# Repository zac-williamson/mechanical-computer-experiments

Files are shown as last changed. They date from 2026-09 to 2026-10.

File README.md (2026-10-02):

# Mechanical computer modules

Build the next 1-bit register from a small collection of reusable mechanical modules. Only these two designs are active:

| Active design | Entry points |
|---|---|
| Modular actuator, carriage and locking bolt | [Viewer](modular-actuator-carriage/Viewer.html) · [Design and print files](modular-actuator-carriage/README.md) · [Build and validation](modular-actuator-carriage/Source/README.md) |
| Latched 1-bit register | [Viewer](planar-register/register-from-multiplexer/Planar%20register/Viewer.html) · [Design, sources and checks](planar-register/README.md) |

Start with the modular actuator/carriage module when developing reusable components. Keep the latched 1-bit register as the assembly reference. It is a level-sensitive write-enabled latch, not the archived clocked master–slave register.

Read [AGENTS.md](AGENTS.md) before making changes. CAD checks do not establish physical strength, friction, wear or reliable switching; consult each design's reported limitations.

All other designs are in [archive/](archive/README.md). They are historical references, not current candidates or starting points. Do not revive them unless explicitly requested.

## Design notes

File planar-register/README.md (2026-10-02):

# Planar register — preserved latch prototype

[Assembly viewer](register-from-multiplexer/Planar%20register/Viewer.html) · [Print layout STL](register-from-multiplexer/Planar%20register/Print%20layout.stl) · [Design and checks](register-from-multiplexer/Planar%20register/README.md)

This preserves the planar write-enabled latch, including the detachable pinned guide and restored rear bolt-retaining lips. It is not an edge-triggered register. The print layout has 20 printed parts. Geometry checks do not establish physical load capacity; the whole-register closing-data race remains unresolved.

This is one of the two active designs. The separate clock-triggered development is archived in `../archive/clocked-planar-register/`; it is not the current assembly reference. Do not overwrite this latch with that design.

## Sources and reproducibility

The original relative directory structure is retained so source scripts keep their paths. `register-from-multiplexer/Source/` contains the generators, viewer publisher and checks. `work/register-before-left-cam` and `work/register-mux-reference/multiplexer` are frozen build inputs, not alternate current multiplexer designs. `Snapshot hashes.json` records byte-exact copies from the working design.

Run `python restore_validation_workspace.py` to reconstruct the validation working directory from the published snapshot. Install `requirements.txt` into an isolated environment. The source README describes the full development build; native-part regeneration additionally requires the BrickLink Studio LDraw library at its documented path. The full build retains assertions for unresolved whole-assembly issues and is not advertised as passing end-to-end.

The focused checks for this revision are `check_bolt_y_restraint.py`, `check_detachable_guide.py`, `check_support_free_prints.py`, `check_frame_printed_clearance.py`, `check_frame_native_contacts.py` and `check_restored_bearings.py`. Published reports accompany the model. No Bambu Studio slicer was used.

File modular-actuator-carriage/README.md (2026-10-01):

# Modular actuator, carriage and locking bolt

Snapshot of the current tested-in-CAD prototype, saved 2 October 2026.

- [Model viewer](Viewer.html), including motion, exploded, print and tiled views.
- [Complete print layout](Print%20layout.stl).
- [Carriage-only print layout](Carriage%20print%20layout.stl).
- Individual `print.stl` files use the recorded print orientations; other component STLs use assembly coordinates. Units are millimetres.

The module tiles on a 72 mm X by 64 mm Z pitch. X follows rods/axles; Z indexes rows; +Y points toward the rear/base. Rod end coupling holes have 7 mm spacing (X = ±32.5 and ±39.5), with two separate pins per joint. Revised rod ends must mate to revised ends. One-pin joints have not been physically validated.

Recent changes include reinforced carriage fork struts, removal of a redundant carriage arm and square shoulder, rounded locking-rod cam-extension tips, and closer rod coupling holes.

## Validation and limitations

The included latest clearance report covers 26 prescribed motion poses; the tiling report covers neighbouring modules and connector insertion. These are geometric checks, not physical force, wear or strength tests. Rod print checks compare layer growth with the previous geometry; existing pin-hole roof overhang flags remain. The complete assembly is NOT certified support-free. Review the slicer preview before printing, particularly carriage overhangs and hole roofs.

[Build and validation instructions](Source/README.md) provide a self-contained rebuild from bundled mesh inputs, plus the full historical Python sources. This is a mesh-based CAD workflow, not a fully parameterized model. `Model.json`, component STLs, and the self-contained viewer preserve the current geometry. Development history is summarized in `Compact module notes.md`; historical claims there should be read with their revision context. `Snapshot hashes.json` records every exported file.

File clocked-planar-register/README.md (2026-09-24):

# Clocked planar register

[Open the current compact model](Compact%20layout.html). It retains the planar register's actuator cores and uses four worm actuators, five clutch rings and eight elastic bands. The earlier full-size assembly remains in `Viewer.html`; the unclocked planar register and multiplexer are separate, preserved designs.

The compact model has direction-coded D, WRITE and CLK inputs, continuous POWER, and Q on the opposite X side. Its two storage stages form a master/slave register. WRITE selects D or feedback Q before the master, avoiding a gated-clock edge when WRITE changes.

- [Current arrangement and sequencing](Compact%20layout/Design.md)
- [Validation evidence and unresolved requirements](Compact%20layout/Validation%20status.md)

The animation uses the same contact-corrected poses as the printed-part collision checks. Native clutch angular windows determine engagement and reversal backlash; a fixed time delay is no longer used. The animation is a quasi-static model, not a physical load test.

Every geometry report must match the current geometry hash. Historical full-size reports, old fixed-delay traces and static assembly-reference poses do not qualify the current compact mechanism. The qualification summary fails closed when required evidence is absent or stale.

## Reproduction order

Use the existing `work/register-print-env/bin/python` environment from the workspace root. Sources are under `current-designs/clocked-planar-register/Source/`.

1. `compact_layout.py` generates parts and the static viewer.
2. `check_compact_gear_phases.py` and `compact_clutch_profiles.py` derive native gear and clutch phases.
3. `compact_phase_operation.py` simulates all 112 transition/initial-Q cases; `compile_compact_contacts.py` resolves actuator contact poses.
4. Run the geometry, motion, retention, timing, load and print screens listed in the validation status.
5. `publish_compact_motion.py` publishes the animation; `compact_qualification_status.py` reports remaining qualification requirements.

Printed structure, materials, band preload, motor acceleration, joint grip and loaded friction are not established by the nominal motion trace. Do not treat a successful script exit as a working-machine certificate.

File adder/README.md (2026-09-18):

# 1-bit adder

Single-level shared-actuator layout: 292 × 111 mm base, 39 printed parts, 30 gears, three actuators and four clutches.

B′ = B XOR SUB; P = B′ XOR Cin; SUM = P XOR A; Cout = P ? A : B′.

Cin drives only its worm actuator. P drives the shared carry/sum actuator; the pinned carriage tie operates both clutches. The carry data drive comes from local A or B′, so Cin does not power a chain of downstream clutch gears.

`Viewer.html` includes axle labels, part selection, pan and axes. The common carriage, lever and bridge meshes come from ../multiplexer. Carry and sum have local shaft-clearance and tie attachment adaptations. The sum fork has no independent lever or upper actuator frame.

This is an engineering prototype, not a print release. The three actuator carriages have a rounded inside-roof relief for the fixed pivot axle, sized for the full 8.675 mm stroke and 0.5 mm nominal radial clearance. Bearing positions, travel, gear count and external dimensions are unchanged.

Current checks pass: all 16 arithmetic cases, 12 gear-pitch checks, fixed supports, mounting and coupling pins, conservative native envelopes, and carriage travel. `Pivot clearance checks.json` checks a continuous swept axle envelope and verifies that the relief does not materially remove the lever's working contact surfaces over the prescribed switching trace (0.001 mm³ mesh tolerance).

A complete print-orientation audit and loaded shared-carriage test remain outstanding. No print layout is supplied. CAD checks do not establish printed friction, wear or loaded reliability.

Rebuild with Sources/build.py, Sources/gear_check.py, Sources/apply_phases.py, Sources/publish.py, then the audit scripts, including Sources/pivot_clearance_check.py. Python dependencies are in Sources/requirements.txt; LDraw is loaded from the local installation. Do not change stage spacing independently of stock axle lengths and connector positions.

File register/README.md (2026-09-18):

# 1-bit register

Position stores one bit. WRITE releases the spring-biased bolt before the input clutch drives the storage carriage. Output enable connects the powered stored value to BUS_OUT.

`Viewer.html` shows the complete assembly, input labels, individual parts and an illustrative operating sequence. `Assembly manifest.json` identifies all 37 printed parts and hardware; `LEGO parts.csv` is the hardware inventory.

Print `Print plate 1.stl` and `Print plate 2.stl`, or use the individually oriented files in `Print parts`. Inspect support placement around the original clutch fork. Do not assume these plates are support-free. Axle bores face vertically in the supplied orientations. Assemble with LEGO friction pins; each base-mounted bearing uses at least two pins. Use 4 elastic bands.

Slide the bolt into the integral front-bridge guide before installing the rear bridge. Install the follower and cam, then the return band. The cam withdraws the bolt 5.2 mm. Only relock with the storage/test carriage at one of its end pockets. Check free motion by hand before applying drive torque.

Current geometric results are recorded in `Printed clearance checks.json`, `Lock checks.json` and `Print checks.json`. These do not validate loaded operation or ABS tolerances. The actuator's physical reliability remains under test.

## Rebuild

Use Python with `Source/requirements.txt` and an installed LDraw library. Run `Source/build.py`, `Source/print_layout.py`, then `Source/publish.py`; run the check scripts after changes. The generator references ../multiplexer directly. No slicer application is required.

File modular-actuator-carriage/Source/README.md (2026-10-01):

# Rebuilding and validating this module

Run from the repository root on macOS/Linux (the throttler uses POSIX signals). The captured environment uses Python 3.14.

```sh
python3.14 -m venv .venv-modular
.venv-modular/bin/pip install -r modular-actuator-carriage/Source/requirements.txt
.venv-modular/bin/python modular-actuator-carriage/Source/work/run_queued_cool_job.py modular-actuator-carriage/Source/rebuild.py
```

The serial runner limits geometry work to one worker at 10% duty and guards memory. It fails closed if the installed Manifold library lacks the expected TBB control API. Output goes to `Source/build/`; committed print files are never overwritten by this command.

## Inputs and editing

`Inputs/` contains the complete assembly and print meshes, viewer animation, and coupling hardware immediately before the final rod-hole-spacing revision. It is intentional source geometry, not a download cache. `rod-pin-spacing/build.py` applies the last hole relocation and rebuilds Model.json, the viewer, individual rod STLs and the full plate. Change the explicit 0.5 mm shifts consistently in rod cuts and coupling-pin placement if editing that parameter. The other components are preserved from their bundled mesh inputs. This design was developed by successive mesh booleans; it is not a fully parameterized CAD model.

`History/` preserves ALL 307 original project Python scripts, including builders, analyses, packaging and validation. These are historical reference, not the supported entry point: many retain original local paths or depend on obsolete candidate snapshots. Use them to understand the geometric construction, then port the desired operation to the current pipeline with the current Inputs. Do not run an old publisher against the current design. No historical private workspace paths are needed for the supported rebuild.

`Switching trace.json`, `native_envelopes.py`, the single-band geometry and the seam-cleaning helper are bundled dependencies. Native hardware meshes are already embedded in Model.json; LEGO Studio is not needed to rebuild or validate the current revision.

## Tests and limits

Rebuild runs 26 mechanism poses, 2x2 tiling and connector insertion, carriage installation around the preassembled actuator, watertightness, and print-oriented layer-growth comparison. Existing rod hole-roof overhang flags are retained and printed; the comparison is not a support-free certificate. Contact exclusions and conservative native-part envelopes are documented in validation code. Test reports establish geometry only, not physical load capacity or reliable operation.

Never infer physical validation from `passed`. Read module README.md, AGENTS.md and Compact module notes.md before editing.

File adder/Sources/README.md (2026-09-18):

See ../README.md. Common actuator source: ../../multiplexer. This is an unprinted engineering prototype.

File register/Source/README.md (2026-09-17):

# Regenerating this prototype

Use Python 3 with the packages in requirements.txt. Set LDRAW_DIR to an installed LDraw library containing parts/ and p/. The default points to the existing Studio 2.0 LDraw library on macOS. No slicer is invoked.

Run build.py, then print_layout.py and publish.py. For verification run check.py, native_check.py, mount_check.py and gear_check.py. Run scripts from this directory or by absolute path. Outputs go to the parent directory; set REGISTER_OUTPUT to a different existing directory to generate a separate copy.

Inputs contains the final multiplexer mesh components and its reference assembly/pose data used by this design, not intermediate design iterations. New structures are parameterised in build.py; inherited actuator components are mesh inputs. This is not a fully parametric solid-CAD model. Viewer.html in Inputs is reference data, not the new register viewer.

LEGO visualisation geometry is loaded from your local LDraw installation. LDraw part authors retain their respective credits and licence terms; those part source files are not redistributed here. The embedded reference and output viewers include derived visualisation meshes. LEGO is a trademark of the LEGO Group; this is an independent prototype.

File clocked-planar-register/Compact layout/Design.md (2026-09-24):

# Compact clocked register

The current static complete-assembly envelope is **278.4 × 127.2 mm in XZ**, a **50.42% area reduction** from the earlier full-size clocked assembly. Overall Y depth is **76.23 mm**, reduced from 99.4 mm. These include shafts, retainers and frame, but are reference-pose dimensions rather than a swept-motion packaging claim.

## Components and routing

There are four planar-derived worm actuators: WRITE selector, master storage, output storage and CLOCK sequencer. Five clutch rings comprise the WRITE selector, two storage outputs and two input-disconnect gates. Eight elastic loops serve four actuator returns, two bolts and two passive fork biases.

D, WRITE, CLK and POWER enter the negative-X side; Q exits positive X. CLOCK uses one reversing mesh. Its inversion is absorbed by the sequencing direction. The selected signal uses one mesh to the master gate; master output directly drives the slave gate input. Q feedback uses one axle and one mesh at either end. The D header's single mesh is oriented in Y around its receiving shaft to clear the master ring without an additional idler or greater Y envelope.

Each storage power branch has unit speed magnitude. Master and slave clutch-side assignments differ to absorb the interstage inversion. The model checks the actual Q shaft's angular velocity; its settled ratio to POWER is +1 or -1, not a value inferred merely from carriage position.

## Clock sequence

The original clock actuator drives a 12 mm / 30 mm amplifier. Its approximately ±3.75 mm stroke produces approximately ±9.375 mm common-bar travel. A rising clock withdraws master drive, permits the master bolt to seat, lifts the output bolt and admits master data to the output actuator. Falling clock reverses the sequence.

Each input fork has 4 mm of one-sided float: elastic bias permits its dogs to wait for angular alignment, while the bar positively withdraws it. The rear fork guides retain their compact positions; only each front clutch finger is offset 6 mm. The gate gears sit alongside their LEGO clutch connectors. Nominal first tip contact is at 6.8 mm bar travel, before full insertion. The model tracks the measured CAD angular windows and about 64 degrees of dog backlash.

Changes to D or WRITE at the capture boundary violate the setup/hold assumption. Those cases are explicitly indeterminate rather than assigned a guaranteed bit. Four such nominal cases leave the master outside a locking pocket. The mechanism must not be described as accepting arbitrary asynchronous captures.

## Structure and manufacture

Supports follow the actual shaft and pin datums. All sixteen routing shaft stacks have opposing nominal thrust faces; grip strength remains a separate requirement. Carriage halves retain bearing-flat print orientations.

The rear clock-pivot bearing is a separate bridge, attached with two non-collinear LEGO friction pins. Its bearing axis and amplifier position are unchanged. This removes the former roughly 31 mm unsupported ledge beneath the base's pivot region. The bridge prints flat on its Y face. Pin-bore roofs and counterbore lips still need bridge-quality verification; the common cam/fork bar has support-dependent features and is not designated support-free.

See [validation status](Validation%20status.md) for the current evidence, failures and limitations. The planar register and multiplexer have not been regenerated or modified by this work.

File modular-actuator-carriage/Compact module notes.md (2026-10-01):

# Compact module candidate

Base footprint: 72 mm X × 64 mm Z, X = −31.5 to +40.5, Z = −8 to +56. Base remains Y = 32 to 48.4; no increase in depth. Moving rod ends extend beyond the base to mate with adjoining modules.

The frame-joining holes remain at Z = 0 and 48, now X = −26 and +35. Only the left bearing-wall pins move along Z, to 10 and 38. The left wall has rear access gaps so connecting bridges can be pressed into place after the walls are mounted. Pin ends remain flush with the base underside at Y = 48.4.

Both rods are shortened 4 mm at each end, carrying their existing lap joints and holes inward. The actuator axle is 9L; the output axles are 4L each. Four half-bush retainers sit 0.8 mm farther inward, in shallow bearing recesses, leaving 0.2 mm to the external connectors. The 72 mm nominal pitch gives 8 mm nominal insertion into each end of a 2L connector. Exact physical seating against the smooth connector centre stop remains a fit test; the reference mesh has a 0.2 mm divider, and keyed mating contacts are excluded from clearance testing.

Checked: operating geometry, 2×2 neighbouring modules with independent rows, bridge and rod-pin insertion, watertight printable components. These are geometric tests, not loaded-operation or physical print validation. Use the updated base, both walls, both rods and frame bridges together; do not mix their positions with the 80 mm version. The carriage, actuator cheeks, bolt and guide geometry are unchanged.

## Rebuilt base

The base now consists of a rear plate and explicit mounting blocks. All four bearing-wall pins have 8 mm-deep sockets; the relocated lower-left socket no longer opens into empty space. Frame-joining pins remain flush with the underside. Connector pockets are open spaces between blocks, without retained cut remnants. The lower actuator bore has an intentional open mouth below Z = 29 on its front portion, removing the thin lip above the cheek clearance; its rear portion remains enclosed.

## Rebuilt left bearing wall

A new continuous 4 mm-thick web joins both mounting feet. The former central rear cutout is filled. The lower axle uses a 7 mm-radius circular boss with an angled shoulder into the wall; minimum radial material at its retainer recess is 3.15 mm. Pin centres, rod-guide clearances and the +X printing face remain unchanged. Rear access above and below the feet remains open for the frame bridges. The lower actuator bearing, rod guides and all mounting positions were checked against the moving module and tiled neighbours.

## Fork-root repair

Replaced the fork-root junction and adjacent brace sections with overlapping solids. Removed the residual thin cut surfaces. The clutch-contact region, worm bearing, locking detents and rod-pin mounting geometry are unchanged. Motion, tiling, carriage insertion and sampled 0.16 mm print-layer checks passed; this does not establish physical strength or friction.

Removed the residual thin bearing-transition projections from both carriage halves. The fork root, braces and working contact regions are unchanged. This change removes material only, so the prior clearance checks remain applicable; both updated parts passed solid and sampled print-layer checks.

Fork reinforcement: widened both 45-degree struts along Y from 2.2 to 3.4 mm (Y=1.55..4.95 and 9.3..12.7). Removed the left carriage cantilever toward the fork. Working worm bearings, clutch contact, detents and rod pin mounts unchanged. Passed 26 motion poses, tiled-module and insertion checks, and sampled 0.16 mm layer island checks. Physical strength and printer results remain untested. Updated matching carriage and complete print layouts.

Removed the unnecessary square shoulder above the fork struts (16.96 mm3 removed; no added material). Braces, fork contact, bearings, detents and pin mounts unchanged. Previous motion/insertion clearances preserved by removal. IMPORTANT: whole-carriage 45-degree layer-growth review flags further overhangs; island checks do not establish support-free printing. See project AGENTS.md mandatory printability rules.

Rounded locking rod cam-extension shoulders with 2 mm root blends and 1.5 mm outer corner rounds in XY. Retained operating XZ curve, maximum Y19.6, bed Z40. Passed 26 motion poses and tiling/insertion checks. Layer-growth comparison at 0.2 mm finds no new steep overhangs; existing end pin-hole roof flags remain. Updated assembled, print-oriented STL and full plate.

Rounded the acute cam-extension tips in XZ using 1.2 mm profile rounding, blending back to the original rod root across Y14.2..16.2. Preserved flat bed Z40. Removal only, central cam X=-8..8 unchanged, one watertight solid, no new steep layer-growth flags at 0.2 mm. Existing pin-hole roof flags remain. Updated print STL and full layout.

Rod end pin spacing reduced 8 to 7 mm: X +/-32.5 and +/-39.5. Both rods and tiled pin hardware updated; nominal minimum outer counterbore ligament 1.05 to 1.55 mm. Original bore and roof profiles translated unchanged; end extents, stroke, cams and carriage attachments unchanged. Motion, 2x2 and insertion checks passed. Print layer growth areas no worse than baseline, existing pin-hole roof flags remain. Revised ends must mate to revised ends. One-pin use not physically tested.

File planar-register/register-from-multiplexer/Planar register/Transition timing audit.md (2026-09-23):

# Timing audit — revised cam

The updated model contains 108 examples across all 12 D/WRITE transitions, including both possible held bits and six assumed speed/phase profiles. It uses hysteretic ±0.4 mm clutch-ring play and first-contact coupling. Time is normalized, not calibrated to a particular motor.

There are no commanded motions through an inserted bolt in these nominal examples. However, the two simultaneous D-reversal / WRITE-closing transitions still have three invalid-HOLD examples each: the memory can stop between its pockets. Closing does not guarantee capture of the old bit. This is a latch timing problem, not cured by the stronger guide.

The animation is an event witness, not a force-driven simulation. It does not establish physical minimum/maximum motor response times, native tooth backlash, loaded release, coasting or freedom from every possible jam. See the JSON for individual cases and the main README for the mechanical checks.

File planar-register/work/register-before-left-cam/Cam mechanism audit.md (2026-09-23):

# Cam / roller / bolt: loaded mechanism review

**Decision: do not print the present complete mechanism as a confidence prototype. The short, offset bolt guide needs revision first.** This review isolates the cam lock; the master–slave architecture and simultaneous-input race are outside its scope.

## Findings from the actual geometry

| Item | Finding | Implication |
|---|---|---|
| Guide engagement | Guide is 7.6 mm high, but the rising stem leaves only 4.6 mm overlap at full lift. | The available bearing span shrinks exactly when the roller is highest. |
| Roller overhang | Near the end of the straight ramp, its centre is 9.94 mm above the guide top; at full lift, 11.8 mm. | Horizontal cam force creates a large overturning moment. |
| Rear offset | Roller centre Y27.6; guide centre Y19.6: 8 mm offset. | Even the upward lifting force twists the bolt into the guide walls. |
| Band offset | Its attachment is approximately 7.4 mm to one side and 1 mm forward of guide centre. | Increasing band strength also increases the tendency to cock the bolt; it is not a cure for a bad guide. |
| Guide play | ±3° tilt with ±0.15 mm translation causes **zero solid intersection** between the complete bolt and guide in 12 checked raised poses. Roller X shifts 0.83–0.89 mm. | The previous total 0.6 mm timing-error assumption is unsupported by the guide alone, before print error, pin play or flex. Other parts/cam were absent in this test; it is not a proof of an assembled tilted trajectory. |

The previously published friction formula accounted only for direct lateral force. It omitted the overhang moment, rear offset and return-band eccentricity. **Its apparent friction margin must not be used.**

## Force and flex screen

A rectangular-guide Coulomb-friction calculation balances the cam force and the wall reactions at both ends of the actual remaining stem overlap. It treats the cam roller as ideal, assumes a 2 N band, and varies friction rather than claiming a measured PLA coefficient.

Near WRITE displacement −0.45 mm (bolt lift 5.94 mm), the screen gives:

| Assumed guide friction coefficient | Required upward roller force | Horizontal cam force | Existing gross-beam cam deflection |
|---|---:|---:|---:|
| 0 | 2.0 N | 3.6 N | 0.019 mm |
| 0.05 | 3.54 N | 6.37 N | 0.033 mm |
| 0.10 | 87.2 N | 157 N | 0.81 mm |
| 0.15 or greater | No positive sliding equilibrium in this screen | — | — |

These are **conditional sensitivity results**, not predicted measured forces or a certified critical coefficient. Face-friction moments, compliance, local corner contact, bush drag and material variation are not solved. They show why the earlier “a 2 N band implies a lightly loaded cam” argument was inadequate. The calculated critical region is sensitive enough that this guide is a poor first-print candidate.

The gross-beam deflection uses the earlier unperforated cam approximation, assumed E=1800 MPa and rigid attachment. Pin-hole stress concentration, shear-key fit, local bearing and frame movement remain excluded; 0.81 mm is not a verified assembly deflection. It demonstrates that modest band tension can produce large structural demand when guide reactions amplify friction. A detailed FEA of the cam alone would not resolve the more fundamental guide/contact uncertainty.

A separate bolt-stem beam screen under residual keeper side load predicts approximately 23.8 MPa bending stress at 50 N and 47.7 MPa at 100 N, using a 5.8 mm tip lever arm. These are screening forces, **not** a demonstrated mapping from 0.1 Nm input torque. The actual distributed keeper contact, guide support, printed orientation and load release need measurement. The bolt must not routinely be asked to release against a driven memory actuator.

With the cam removed from contact, the off-centre band can also cock the raised bolt. The simple guide model's return friction limit falls from about 0.45 at low lift to 0.27 at full lift. A stronger band scales both useful pull and friction-generating reaction together.

## What must change in the mechanism

1. **Guide the roller carrier near where the force enters.** Use two separated guide lands or a guided crosshead, keeping the roller within their support span rather than above a short stem sleeve.
2. **Maintain guide overlap through the entire lift.** Do not lose almost half the bearing length when opening.
3. **Centre the cam and return-band loads on the supported carrier as closely as possible.** Keep the narrow locking tip as an extension of that supported carrier; do not use it as the sole anti-tilt guide.
4. **Recalculate the cam sequencing with actual maximum play plus flex.** Do not recover timing margin by assuming a tighter print than the 0.4 mm-nozzle process supplies.
5. **Check attachment and frame deflection together.** Thickening the orange plate alone would transfer increased force into the guide and LEGO-pin joint without curing wedging.

These are design requirements, not an integrated CAD revision. No assembly STL has been altered in this review. Once the carrier layout is chosen, its complete travel and print orientation need new checks before it becomes a print candidate.

## Small-test scope after that revision

The existing `Latch coupon` tests an earlier bolt/keeper arrangement moving along Y. It does **not** reproduce this Z-moving cam, roller offsets, guide overlap or orange pin joint, and must not be used to qualify them.

The useful replacement test assembly must reproduce the actual cam, roller/axle/retainer, carrier guide, band anchors, keeper, and cam mounting joint. Drive the cam manually first, measuring force through the full stroke in both directions and at both keeper positions. Then use the actual WRITE actuator. Preserve representative support spans so the fixture does not hide frame flex.

Record: printed dimensions and free play; band force versus extension; peak cam force in each direction; complete bolt withdrawal and insertion; roller/guide displacement under load; pin-joint slip; performance after repeated cycling. Test deliberate mid-pocket stops using the compliant band return. These establish whether the revised cam lock operates, not a complete register torque rating.

Only after measuring the working mechanism's demand should we test the intended 0.1 Nm on each relevant axle with the actual driveline and output load. A 100 mm torque arm with 1 N tangential force represents 0.1 Nm, but does not establish the corresponding bolt load through a worm train. No motor RPM or filament datasheet substitutes for these measurements.

## Evidence and reproducibility

- `Loaded guide screen.json`: 751 travel positions, seven friction values; actual geometry source hashes and explicit statics assumptions.
- `Bolt guide play.json`: exact solid intersection checks for the 12 tilted guide-only poses.
- Reproduce using `Source/audit_cam_loading.py` and `Source/audit_bolt_play.py` in the supplied CAD Python environment.
- Prior nominal collision checks remain nominal geometry checks; they omit these free-play poses and elastic deformation.

The general eccentric-load binding concern is also explained by [igus's linear-guide design guidance](https://www.igus.com/company/linear-guides-the-2-1-rule-ca). Its product-specific 2:1 rule is **not** used as a PLA design limit here; our figures come from the explicit geometry and stated model.

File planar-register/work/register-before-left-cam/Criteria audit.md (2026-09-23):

# Direct-cam criteria audit

The direct-cam revision removes the crank and its support scaffolding, integrates the bolt guide into the existing bearing cheek, and lowers the rear backbone to the actual mounting regions. It uses 19 printed parts and 80 modelled LEGO pieces.

Original multiplexer worm/reaction/rocking-lever operation and bearing print faces are retained. Moving and structural additions use genuine LEGO axles, bushes and friction pins. The separate cam plate has a fully supported flat print face.

Current numerical evidence is in Operation checks.json, Operation hardware checks.json, Rotating clearance checks.json, Actuator addition checks.json, Actuator band checks.json, Qualification.json, Carriage printing checks.json and Criteria audit evidence.json. These reports have different scopes; none is a physical qualification.

The principal remaining risks are loaded clutch engagement, the steep cam's sensitivity to guide friction, actual pin/axle fits, local contact stress, print quality, and survival of 0.1 Nm in all blocked conditions. Flex screening is conditional, and inherited native LEGO meshes include open surfaces. Full compliance with the original working/torque/continuous-collision criteria is not established.

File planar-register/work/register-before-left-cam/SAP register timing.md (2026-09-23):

# Ben Eater register timing and implications for this latch

Ben's A and B registers use 74LS173 devices with independent clock and load-enable inputs. Data is captured on the positive clock edge when enabled. Load-enable is not a transparency control. The device requires data/enable setup and hold timing around that edge. See [A register schematic](https://eater.net/schematics/a-register.png), [B register schematic](https://eater.net/schematics/b-register.png) and [TI 74LS173 datasheet](https://eater.net/datasheets/74ls173.pdf).

The microstep counter receives inverted CLK, so its normal step advance occurs on the system's falling edge. The following rising edge captures the selected transfer, after time for control and data to settle. This describes intended synchronous operation, not a claim that EEPROM glitches or all hardware timing hazards are impossible. See [control schematic](https://eater.net/schematics/control.png).

Ben's ADD microcode changes from `RO|BI` (RAM drives bus, B enabled) to `EO|AI|FI` (ALU drives bus, A and flags enabled). Consequently the bus data and B's load-enable can change as part of the same microstep boundary. A's enable also asserts while the bus source changes. They need not arrive at precisely the same physical instant. SUB has the analogous change with SU asserted. See [Ben's original microcode](https://github.com/beneater/eeprom-programmer/blob/master/microcode-eeprom-with-flags/microcode-eeprom-with-flags.ino).

There is no separate ALU result register in this design. The adder/subtractor is combinational; arithmetic results are captured in A. The flags and display output register are separate storage. See [ALU schematic and description](https://eater.net/8bit/alu).

## Consequence for the mechanical design

The correct target is to retain the data sampled at a defined capture phase. Ben's design does not require a deterministic old/new choice if D violates setup/hold at the actual capture edge. Simultaneous microcode-enable and data changes are safe only because capture is a separate event.

The current mechanism is a level-sensitive latch. Connecting AI or BI directly to its WRITE shaft does not reproduce Ben's edge-triggered register. In particular, ADD feeds A through the ALU and bus back into A: while a transparent A latch is open, changing A changes its own input again. For A=3 and B=2, the intended one-time capture is 5; continued transparency exposes the next sum 7, then further changes (actual asynchronous bit behaviour need not follow clean integer steps).

A mechanically sequenced capture system can use this latch as a building block, consistent with the original scope allowing clock sequencing to be separate. However, it must preserve old source values during acquisition, close/isolate the receiving storage before bus/control changes, and prevent ALU feedback while A updates. Two storage stages operated with non-overlapping phases are one candidate; a separate temporary result stage plus additional microsteps is another. Neither has been implemented or qualified here. Simply connecting WRITE=enable AND clock, or slowing all motors, is not a demonstrated solution.

The simultaneous-close race in the transition audit remains a valid limitation of the bare latch. It is not by itself proof that an externally sequenced mechanical SAP cannot use a revised/qualified version of it. Treat arbitrary simultaneous D/WRITE capture as a stress case; derive allowed operational timing from the eventual clock architecture. No full-register print recommendation follows until that timing and mechanical binding behaviour are qualified.

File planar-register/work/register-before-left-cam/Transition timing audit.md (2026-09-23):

# Transition timing audit — do not print this revision yet

**Scope update:** The user has revised the timing question to match Ben Eater’s SAP. See [SAP register timing](SAP%20register%20timing.md): clock capture is separate from load-enable changes. The following is the bare-latch simultaneous-transition stress audit under the earlier old-bit assumption, not a requirement that Ben’s chips resolve setup/hold violations.

Earlier stress-test requirement: when D reverses at the same time as WRITE changes from 1 to 0, retain the **old** bit. The current mechanism does not establish this. It has a race between D moving the memory actuator and WRITE disconnecting its drive. The cam sequences isolation and bolt insertion, but it does not prevent the memory moving during the isolation stroke.

## What was wrong with the previous evidence

The previous transition audit moved WRITE first and memory second. Enumerating all input pairs did not make those paths simultaneous. The viewer used `qe > 0.4` and bolt lift greater than 5.8 mm to permit memory movement; that condition enforced the desired behaviour instead of deriving it from the clutch. Clutch ring displacement was a function of carriage position only and omitted reversal history. Thus the previous collision results remain sampled geometry checks, not functional qualification of these transitions.

## Revised model and evidence

The viewer now includes all 12 directed changes, both possible stored bits whenever starting in HOLD (18 initial-state cases), and six timing/contact examples (108 runs). It allows the actuators to move concurrently. Each clutch ring has direction-dependent fork play: its previous position stays unchanged while inside the interval carriage position ±0.4 mm, then follows the pushing face. This is the existing nominal CAD allowance, not measured LEGO tolerance.

Torque transfer is considered possible as soon as dogs contact, without waiting for full axial engagement. Angular take-up can be zero when a driving flank is already aligned. A delayed-reversal example illustrates the opposite ordering; its delay is an assumption, not a measured upper bound. The model stops the memory immediately when the D clutch separates: even this optimistic no-coasting assumption produces failures.

The ring extends to ±11.2 mm and the facing gear begins at ±12 mm. Consequently 0.8 mm ring displacement is the earliest outer-envelope overlap. A native triangle-surface sweep (360 relative phases, 0.025 mm axial increments) first detects contact at 1.95 mm. This is a sampled geometric observation, not a calibrated engagement threshold or a guarantee about chamfers, deflection or loaded contact. Both the conservative envelope and this mesh-contact example are included. The mesh scan is saved separately.

Time units are normalized: WRITE carriage speed is 1 mm/unit. Equal carriage speeds are an illustrative favourable assumption, not an assertion that equal motor RPM produces identical travel histories. The other ratios are sensitivities, not measured speed tolerances.

## Concrete counterexample

Start with D=1, WRITE=1, Q=1. Reverse both inputs. With the mesh-contact example, no reversal take-up delay and equal carriage speeds:

- WRITE retreats from +3.75 mm; its ring follows the withdrawing fork face after the nominal lost travel.
- D stays coupled until WRITE reaches approximately +1.55 mm.
- During that interval the memory carriage moves from −3.75 mm to approximately −1.55 mm.
- D then disconnects. The memory is outside either full-insertion pocket position (which requires |q| ≥3.3 mm within the operating stroke).
- The return band cannot push the bolt through the solid keeper. The assembly finishes HOLD **not locked**, with the output at the edge of its clutch-contact region, not a reliably retained state.

For the 1.5× memory-speed example, the old output clutch releases around normalized t=1.47; D isolation occurs around t=2.21. This violates the requested ordering directly. Memory stops around −0.45 mm, leaving Q undriven. At 4×, memory reaches the other pocket and locks the **new, wrong** bit. With enough reversal delay the old bit survives. This range of outcomes is the race; backlash cannot be treated as a safety feature.

## All twelve transitions

Pairs below are (D, WRITE). “Conditional” means the prescribed contact-event examples reach the intended endpoint, **not** that the axle loads, tooth phases, reaction times or physical operation pass.

| Start | End | Result |
|---|---|---|
| 00 | 01 | Conditional: acquire 0; checked starting with either stored bit |
| 00 | 10 | Conditional: remain locked; D isolated |
| 00 | 11 | Conditional: acquire 1; simultaneous reversal and unlock |
| 01 | 00 | Conditional: retain 0 if initially settled |
| 01 | 10 | **Fails old-bit retention guarantee; can stop between pockets or capture 1** |
| 01 | 11 | Conditional: switch to 1 while writing; output transfers through a neutral interval |
| 10 | 00 | Conditional: remain locked; D isolated |
| 10 | 01 | Conditional: acquire 0; simultaneous reversal and unlock |
| 10 | 11 | Conditional: acquire 1; checked starting with either stored bit |
| 11 | 00 | **Fails old-bit retention guarantee; can stop between pockets or capture 0** |
| 11 | 01 | Conditional: switch to 0 while writing; output transfers through a neutral interval |
| 11 | 10 | Conditional: retain 1 if initially settled |

Starting from an unsettled previous write adds further interruption cases; twelve input pairs alone do not cover the continuous internal state or input chatter.

## Ordering and axle binding

There are three distinct requirements:

1. Isolate D before the memory loses the old output clutch engagement.
2. Isolate D before the lock bolt can obstruct memory travel.
3. Actually seat the bolt in the **old** pocket, rather than stop over the solid keeper.

The current mechanism does not enforce 1 or 3. Nominal cam geometry favours 2: first bolt-tip intrusion is at WRITE q≈−0.75 mm, whereas the conservative earliest-contact clutch envelope is separated below q≈+0.4 mm on withdrawal. That is a nominal 1.15 mm sequencing interval, not a time margin or a force proof. The previous 0.6 mm cam-error assumption was not measured and is not a worst-case tolerance stack.

| Axle / load path | What remains unresolved |
|---|---|
| D → WRITE dog clutch → memory worm | Loaded dog withdrawal can resist WRITE motion. If the bolt obstructs a still-driven actuator through lag, flex or sticking, the worm drive can stall or overload. Disconnection stops commanded drive, not necessarily stored torsional energy or inertia. |
| WRITE → actuator → cam | The steep cam, guide side load, band force and loaded clutch release can stall WRITE; no finite maximum closing time has been established. |
| POWER → opposing-direction memory clutch gears | Nominal rigid axial envelopes do not allow the ring to reach both gears at once (one needs r≥+0.8 mm, the other r≤−0.8 mm). This excludes that particular rigid double-engagement path, not all power binding. Tooth-on-tooth entry, shallow engagement and output reversal under load remain unqualified. |
| Q | Its inertia and connected load affect clutch impact and release. A neutral interval means Q can coast or stop; it is not a commanded 0 or 1. |

Locking the memory carriage fixes its **axial** position; it does not inherently brake Q. A power jam needs an actual rotational reaction path such as obstructed clutch engagement or a blocked output. The current kinematic model cannot prove every axle free from binding, and it should not label a possible jam as an observed one.

## Backlash and minimum/maximum reaction time

For a measured angular take-up β degrees and relative speed n RPM at that interface, the ideal take-up time is β/(6|n|) seconds. Gear ratios must reflect each interface's backlash to the relevant shaft. Fork axial play is a separate hysteresis, not the same quantity as angular dog clearance. Motor reversal, worm/reaction-lever phase, output load, guide friction, elastic deflection and coast add further delays.

The conservative earliest angular reaction is **zero take-up delay**. A finite latest reaction cannot presently be justified: relative speed can fall to zero or a tooth/guide can stall. The available CAD contains neither measured backlash bounds nor a motor torque-speed/load model. Therefore a finite numerical timing certificate would be invented. Equal nominal D, WRITE and POWER RPM does not remove those uncertainties. Inertia and available torque also make absolute RPM relevant.

To guarantee old-bit retention, the maximum memory movement before isolation and residual motion must fit inside the old pocket's remaining travel margin: nominally **0.45 mm** toward the other bit from either ±3.75 mm endpoint. This is much stricter than merely retaining partial output clutch engagement. In timing form, the design needs a justified bound on the integral of memory travel from simultaneous reversal through complete D isolation, including recoil/coast; or a positive mechanism preventing that movement. Incidental backlash cannot supply a guaranteed minimum delay across all phases.

## Required before a print recommendation

The closing race needs a mechanism or an input timing contract that holds the old memory position throughout D isolation. A timed contract would require D remain stable until closing completes, which does **not** meet the requested arbitrary simultaneous-change behaviour. A mechanical revision must provide deliberate isolation priority or bounded data delay and then be checked against worst-case reaction times; a faster nominal WRITE actuator alone is insufficient.

Before qualification, measure actual clutch first/last torque-carrying axial positions in both directions, fork play, angular lost motion at all relevant phases, loaded release force, actuator reversal travel versus angle, cam/guide friction and clearance, and coast under the intended Q load and 0.1 Nm torque. These can be investigated on LEGO subassemblies and a small guide/cam coupon rather than committing to the full six-hour print. They still would not cure the demonstrated sequencing race by themselves.

**Decision: do not print the complete current revision expecting a reliable register.** The geometry clearance reports are retained, but the functional transition audit fails the stated old-bit retention requirement. The viewer is now an explicit contact-event investigation, not a demonstration that the mechanism works.

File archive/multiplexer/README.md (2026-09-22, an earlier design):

# Multiplexer — current design

This is the sole current multiplexer design. Open [Viewer.html](Viewer.html) for the complete assembly and switching animation. The root-level STLs are generated outputs. Run `python Source/build.py` to regenerate the ten parts, hardware data, viewer and print layout. LEGO geometry is in hardware.npz with hardware.json identifying components.

The clutch axle is at Y=10.2 mm, Z=0; the worm axle is at Y=10.2 mm, Z=16 mm. The 16 mm centre distance accommodates two standard LEGO 16-tooth gears. That optional gear pair is not installed in this assembly. Cheek mounts and the band anchor remain on +X. The carriage consists of two printed parts joined by two LEGO friction pins.

## Printing and assembly

Use [Complete print layout.stl](Complete%20print%20layout.stl); its ten printed components are separated and placed on the bed in their intended orientations. LEGO hardware is excluded. Print layout manifest.json records source hashes, orientations through printed-parts.json, and bed contact. Use standard PLA with a 0.4 mm nozzle. No Bambu Studio CLI is used. A bed-contact check is not a slicer-based support assessment.

Fit the rubber band before closing the bearing cheeks. Install the worm and carriage on the baseboard guide before closing the side frames. The front carriage joining pin stays below the clutch gears; the rear joining pin follows the relocated worm bearing.

## Maintenance and validation

Install `Source/requirements.txt`, then run:

- `python Source/build.py` — regenerate the current design in place.
- `python Source/build.py --output /tmp/multiplexer-build` — build into a separate empty directory.
- `python Source/verify_build.py` — clean rebuild; require byte-identical part STLs and print layout against the accepted revision.
- `python Source/check.py`, `python Source/check_envelopes.py`, `python Source/check_fork.py` — geometry checks.

`Source/generate_parts.py` contains the recovered final construction operations. Its exact mesh and hardware inputs are committed in `Source/construction-inputs/`, with hashes. The original workflow was incremental: it operated on earlier geometry. Those inputs are build dependencies, not alternative current designs, and are deliberately retained rather than pretending the workflow was fully parametric. No Trash, external project, or Git-history lookup is needed to build.

`Source/construction/` preserves the recovered upstream scripts that originally created those inputs. They use their original development paths and are provenance, not supported entry points; use `Source/build.py`. This repair restores the original reproducible build, without refactoring its geometry. `Source/accepted-output-hashes.json` records the approved outputs; update it only after an intentional, reviewed geometry change.

The small `Source/Clutch interface reference.stl` is a contact-test fixture, not another carriage or design.

Checks cover fixed/moving printed interference, sampled switching poses with native LEGO meshes, full-rotation clearance envelopes, the elastic band sweep, worm/guide insertion, and added material around the original clutch interface. Inspect the JSON reports; these scripts report findings rather than certifying load capacity. CAD checks do not prove low friction, wear life, or 0.2 Nm endurance for this revision. The physically tested predecessor remains available in Git history.

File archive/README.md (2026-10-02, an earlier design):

# Archived designs — inactive

These designs were retired from the active repository on 2 October 2026. They remain here for recovery and explicitly requested historical investigation. Do not use them to choose the current design.

| Archived folder | Historical subject |
|---|---|
| adder/ | 1-bit adder study |
| cam-test/ | Register cam experiments |
| clocked-planar-register/ | Clocked planar-register studies |
| multiplexer/ | Earlier standalone multiplexer |
| register/ | Separate clocked-register development |

`Repository checks.json` is a historical report and does not describe today's active folder layout. Source scripts and documents in this archive may retain old paths; they are not maintained build entry points. Local uncommitted work, where present, has been retained at the corresponding archived paths.

The active designs are listed in the [repository README](../README.md). The latched 1-bit register remains active at [planar-register/](../planar-register/README.md).

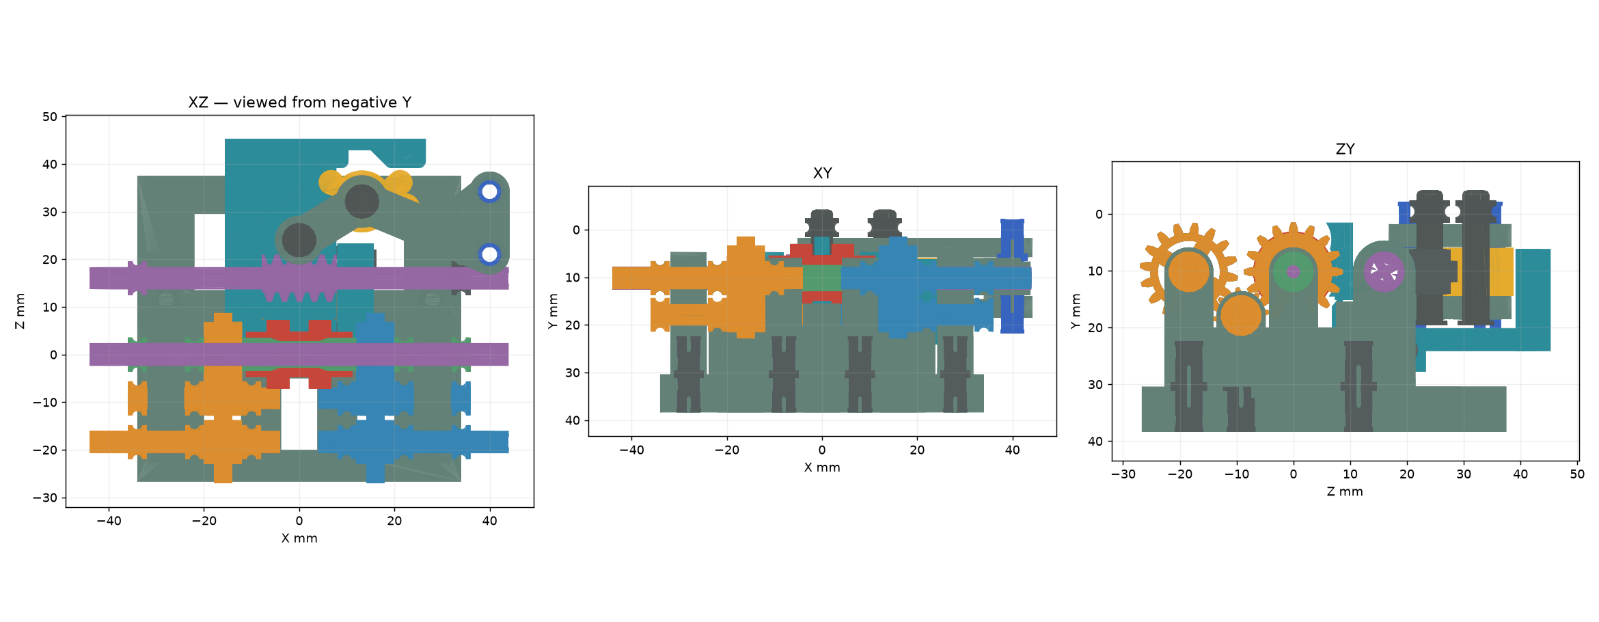
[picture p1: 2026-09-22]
planar-register/work/register-mux-reference/multiplexer/orthographic.png

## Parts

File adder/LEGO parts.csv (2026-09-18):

Part | Quantity
10928.dat | 11
18946.dat | 8
18947.dat | 4
23948.dat | 1
26287.dat | 4
2780.dat | 79
32123a.dat | 55
32905.dat | 3
3705.dat | 4
3706.dat | 4
3707.dat | 12
3713.dat | 6
3737.dat | 2
4019.dat | 8
44294.dat | 2
59443.dat | 4
60485.dat | 4

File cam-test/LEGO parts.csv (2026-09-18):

Part | Quantity
10928.dat | 2
18946.dat | 1
18947.dat | 1
26287.dat | 1
2780.dat | 40
32073.dat | 1
32123a.dat | 32
32905.dat | 2
3706.dat | 4
3713.dat | 5
3737.dat | 5
60485.dat | 2
6538a.dat | 1
94925.dat | 1

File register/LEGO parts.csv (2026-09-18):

Part | Quantity
10928.dat | 6
18946.dat | 4
18947.dat | 3
26287.dat | 3
2780.dat | 72
32073.dat | 5
32123a.dat | 71
32905.dat | 3
3706.dat | 6
3708.dat | 1
3713.dat | 8
3737.dat | 9
60485.dat | 3
6538a.dat | 2
94925.dat | 4

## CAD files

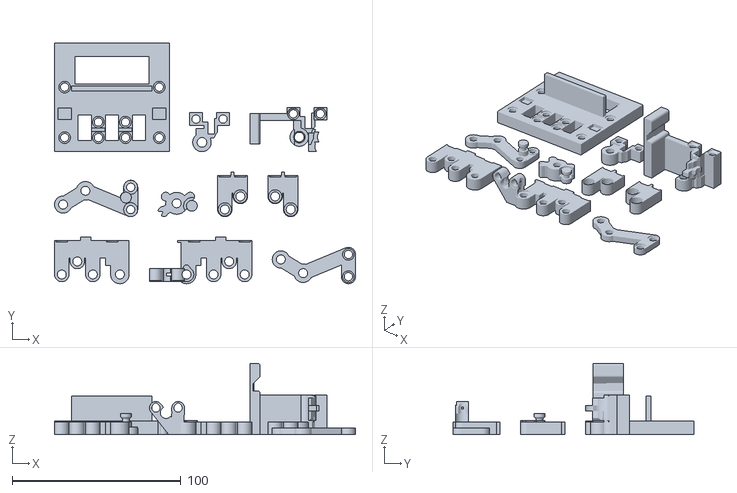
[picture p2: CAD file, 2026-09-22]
planar-register/work/register-mux-reference/multiplexer/Complete print layout.stl
178.2 x 142.4 x 42.2

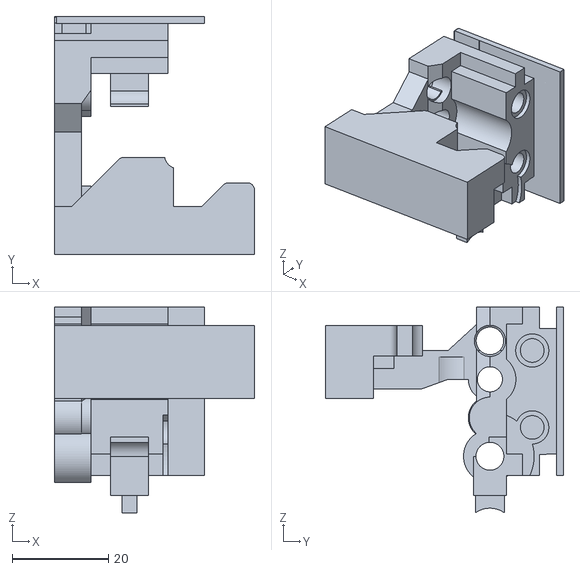
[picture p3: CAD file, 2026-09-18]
adder/C Left carriage half.stl
41.6 x 49.5 x 42.8

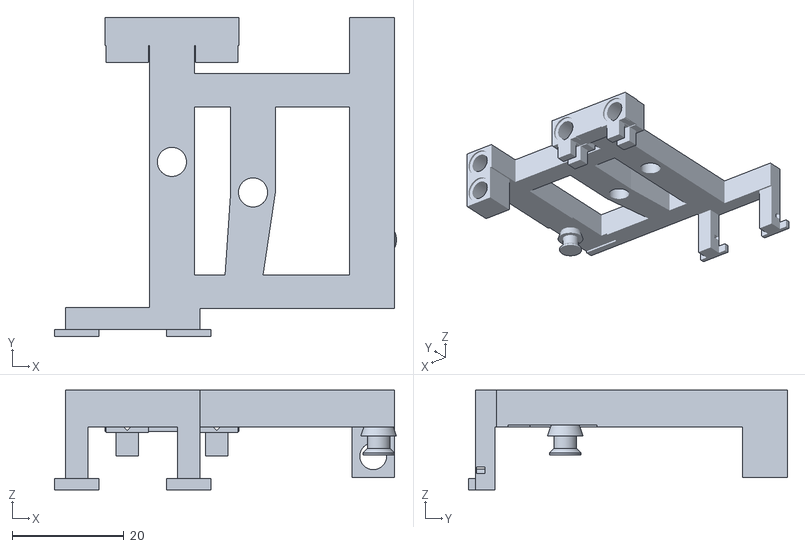
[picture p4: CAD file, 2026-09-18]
cam-test/K Rear bridge and band anchor.stl
61.2 x 57.0 x 17.8

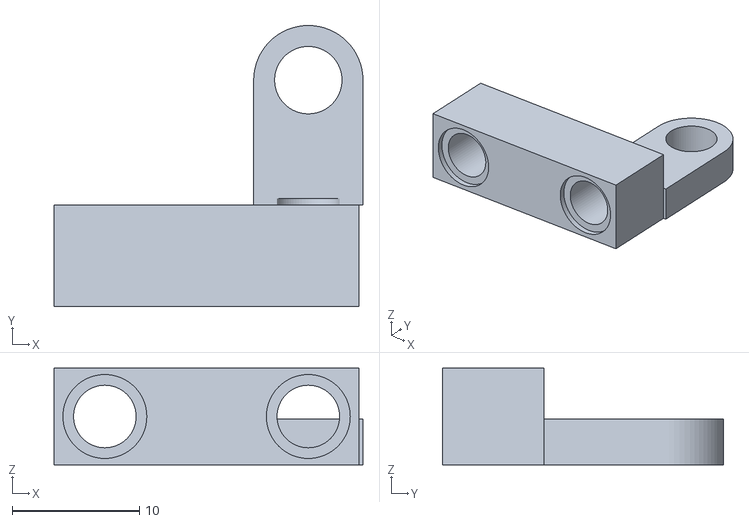
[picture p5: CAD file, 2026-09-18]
cam-test/Print parts/W left bearing.stl
24.3 x 22.1 x 7.60

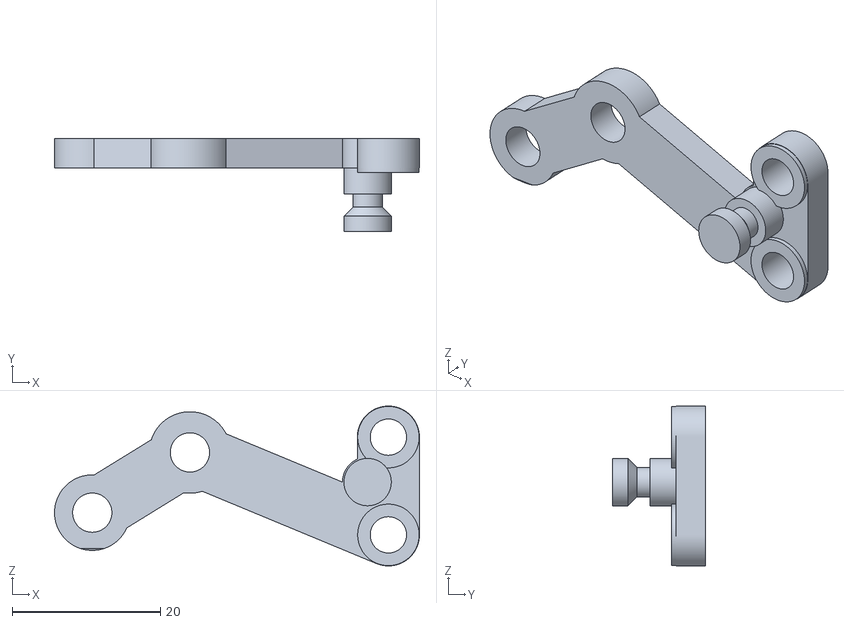
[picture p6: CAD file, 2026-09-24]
clocked-planar-register/Assembly development/slave Rear bearing cheek.stl
49.3 x 12.6 x 21.6

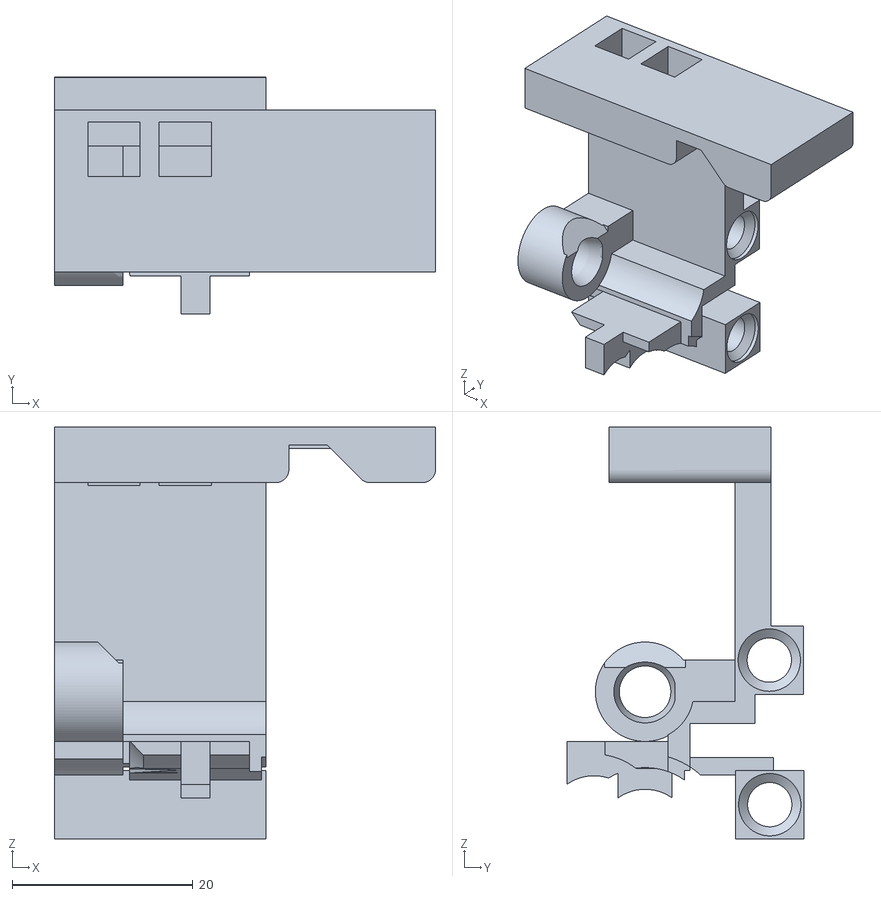
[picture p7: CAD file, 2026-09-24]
clocked-planar-register/Cam study/Slave carriage.stl
42.2 x 26.2 x 45.6

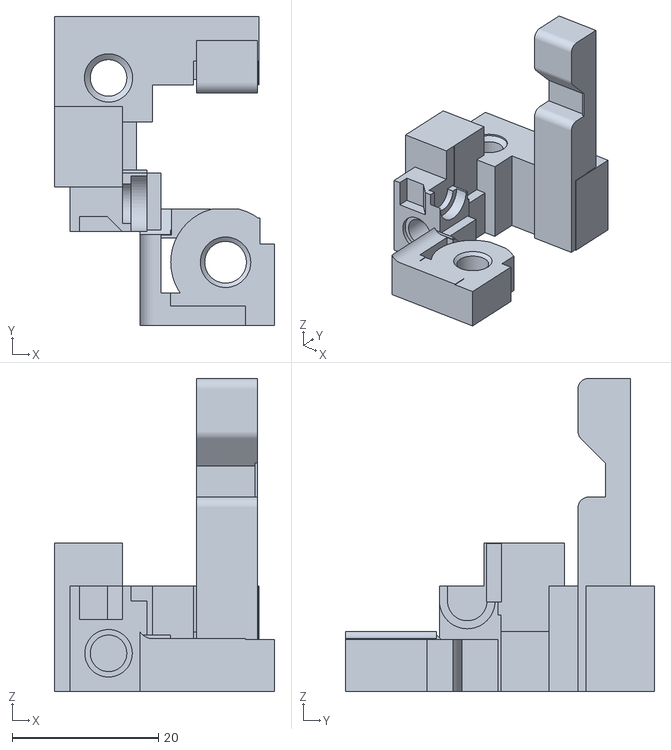
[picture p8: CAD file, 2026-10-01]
modular-actuator-carriage/Carriage bearing end print.stl
30.1 x 42.2 x 42.8

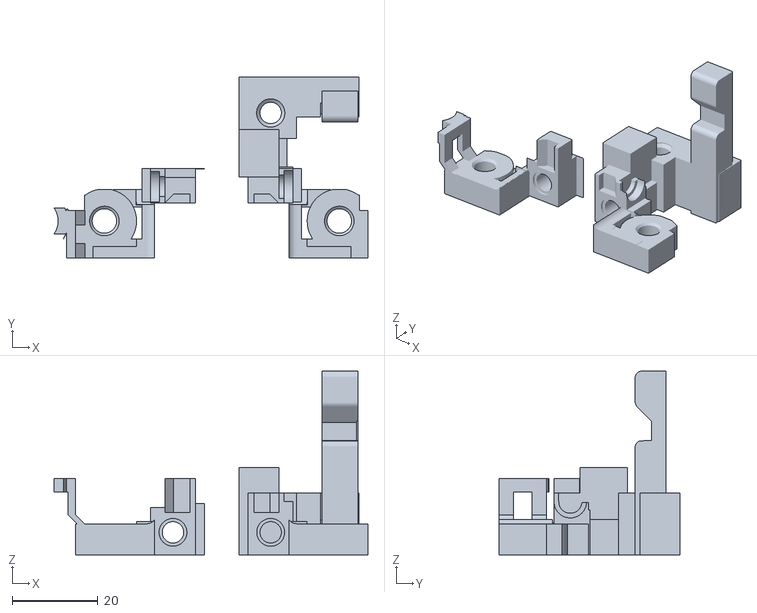
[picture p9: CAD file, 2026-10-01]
modular-actuator-carriage/Source/Inputs/Carriage print layout.stl
73.3 x 42.2 x 42.8

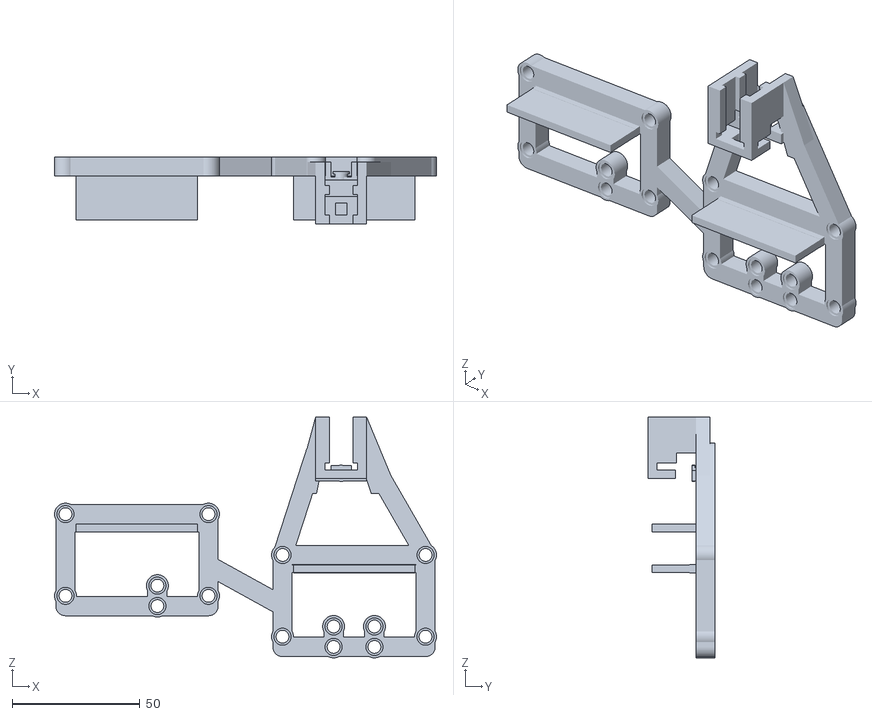
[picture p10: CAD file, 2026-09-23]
planar-register/frozen-inputs/Frame before detachable guide.stl
149.6 x 26.4 x 94.3

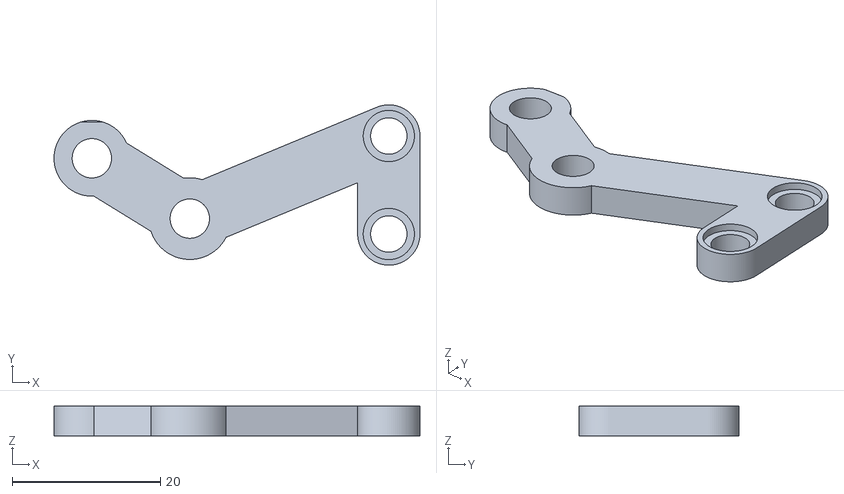
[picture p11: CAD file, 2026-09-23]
planar-register/register-from-multiplexer/Planar register/Prototype print parts/Write — Front bearing cheek.stl
49.3 x 21.6 x 4.00

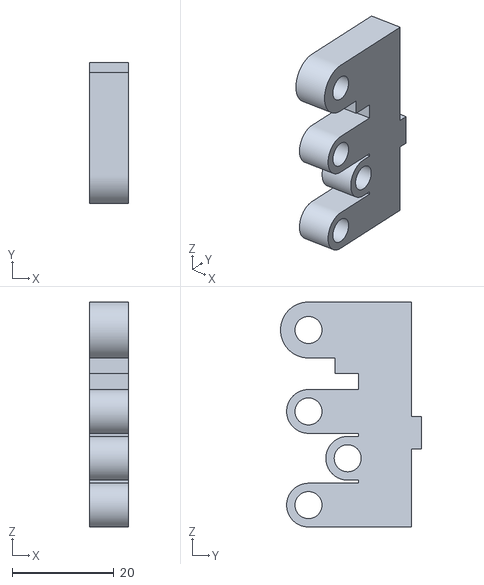
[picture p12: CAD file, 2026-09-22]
planar-register/work/register-mux-reference/multiplexer/Left side frame.stl
7.60 x 27.7 x 44.2

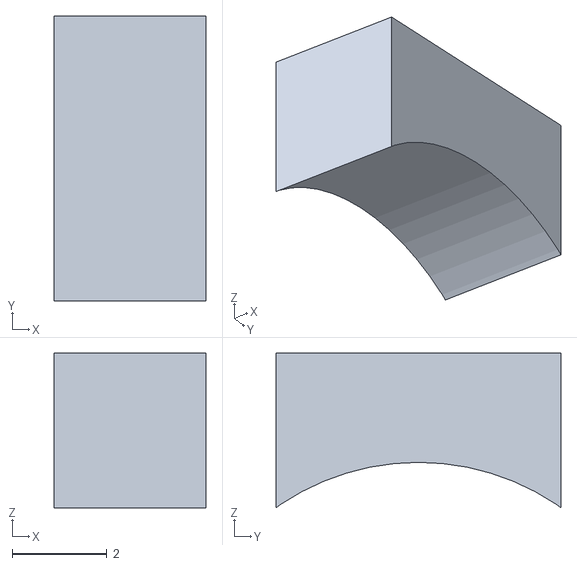
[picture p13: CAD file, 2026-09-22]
planar-register/work/register-mux-reference/multiplexer/Source/Clutch interface reference.stl
3.20 x 6.00 x 3.26

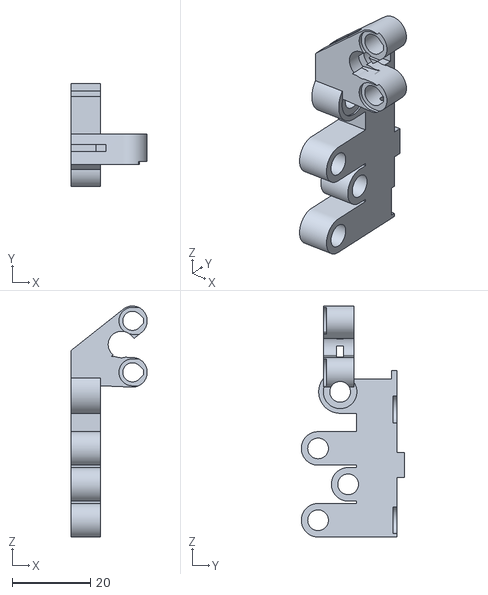
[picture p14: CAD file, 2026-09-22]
planar-register/work/register-mux-reference/multiplexer/Source/construction-inputs/Right side frame.stl
19.6 x 26.5 x 59.2

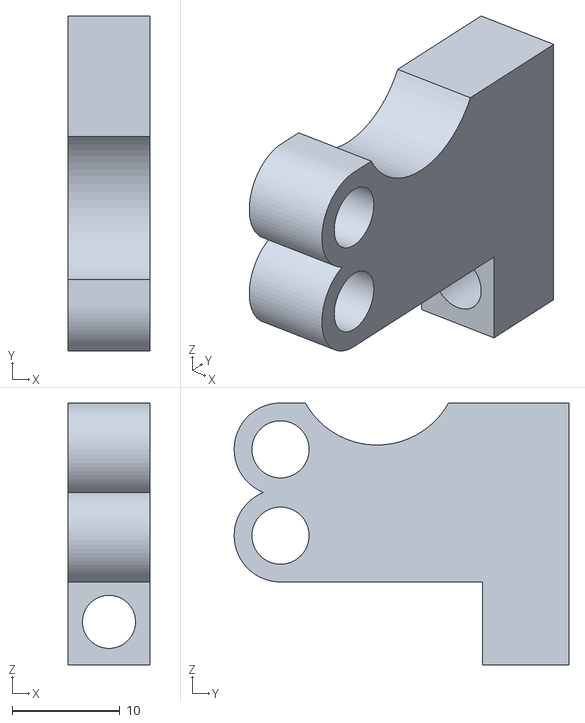
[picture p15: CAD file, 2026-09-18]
register/K inner bearing -4.stl
7.60 x 31.0 x 24.3

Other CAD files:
register/Print parts/W port bearing.stl
adder/P Left carriage half.stl
cam-test/K Right carriage half.stl
cam-test/Print parts/W Bearing wall X26.stl
adder/Base.stl
adder/C Direct lever and band cleat.stl
adder/C Front actuator bridge.stl
adder/C Front bottom guide.stl
adder/C Rear bridge and band anchor.stl
adder/C Right carriage half.stl
adder/C signal bearing -24.stl
adder/C signal bearing 24.stl
adder/P Direct lever and band cleat.stl
adder/P Front actuator bridge.stl
adder/P Front bottom guide.stl
adder/P Rear bridge and band anchor.stl
adder/P Right carriage half.stl
adder/P compound bearing.stl
adder/P guide bearing -24.stl
adder/P guide bearing 24.stl
adder/P signal bearing -24.stl
adder/P signal bearing 24.stl
adder/S Front bottom guide.stl
adder/S Left carriage half.stl
adder/S Right carriage half.stl
adder/S compound bearing.stl
adder/S guide bearing -24.stl
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

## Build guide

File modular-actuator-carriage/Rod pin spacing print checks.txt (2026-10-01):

Waiting for the shared geometry slot.
CPU throttle: 50 ms running, 450 ms paused; one worker, low priority.
Priority adjustment unavailable; one-worker and external 10% duty-cycle limits remain active.
Geometry job: single TBB/BLAS worker, low priority, 1.2 GiB memory guard.
Carriage control rod [[6.4, 50.415, [3.3664648085832596, 0.0, 84.233533680439, 8.0]], [6.6, 6.079, [3.212912268936634, 6.602000571787357, 12.387086197733879, 8.0]]]
Passed print-oriented layer-area comparison for Carriage control rod
Lock control rod [[10.6, 20.542, [3.3664648085832596, 3.999999761581421, 84.233533680439, 10.40000033378601]], [10.8, 6.079, [3.212912268936634, 10.602000333368778, 12.387086197733879, 11.999999761581421]]]
Passed print-oriented layer-area comparison for Lock control rod

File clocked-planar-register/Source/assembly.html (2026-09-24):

# Clocked planar register · full development assembly

Clearance audit in progress — not print-ready. Animation follows the planar actuator's angle-driven contact model, but does not prove strength, friction, tooth engagement or assembly clearance. Both storage stages use the planar carriage, bolt and guide.

Play captureXZ viewOblique

Loading geometry…

Example: D=1, WRITE=1, CLK rises; Q starts at 0. Drag to orbit and scroll to zoom. Teal: storage stages. Orange: clock control and forks. Yellow: locking bolts.

Design status · Fixed-part audit · Operation report

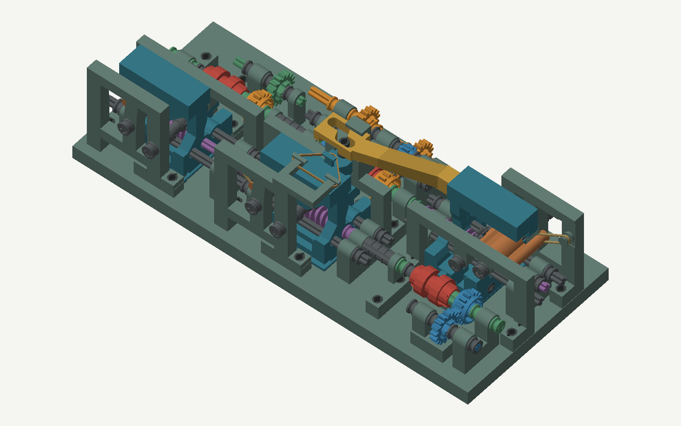
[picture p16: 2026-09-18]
register/Assembly.png

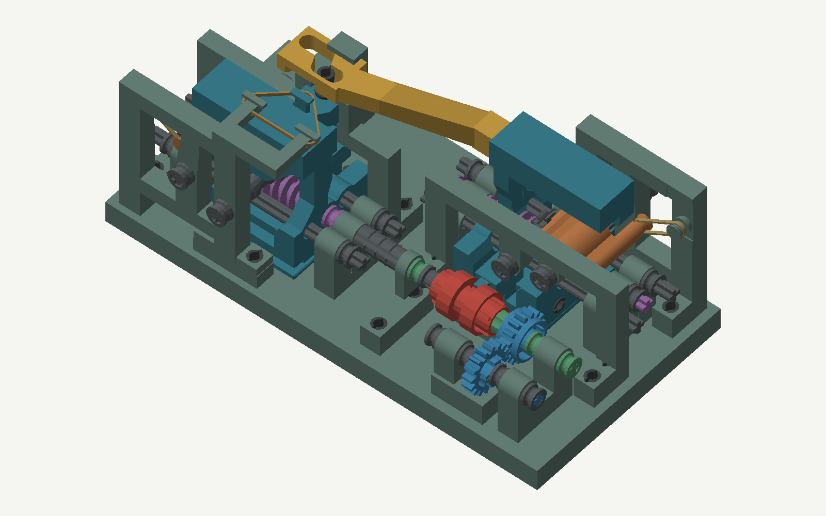
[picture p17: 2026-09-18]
cam-test/Assembly.png

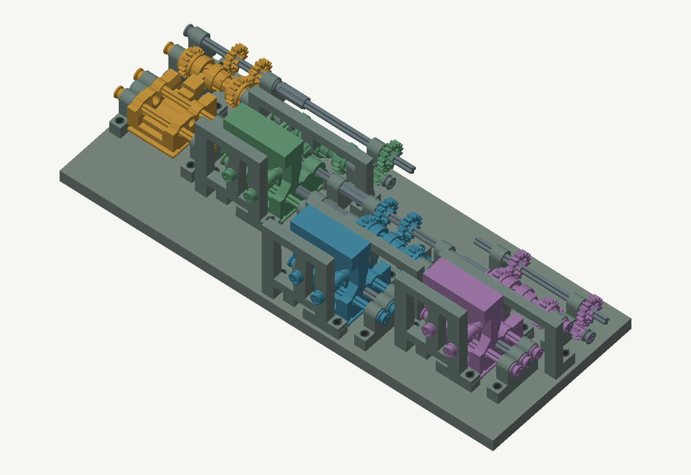
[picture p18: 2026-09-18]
adder/Assembly.png

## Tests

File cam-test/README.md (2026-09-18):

# Register cam test

Two actuators isolate the register cam and lock. CAM CONTROL withdraws the bolt before its clutch allows TEST DRIVE to move the other carriage.

`Viewer.html` shows the complete assembly, input labels, individual parts and an illustrative operating sequence. `Assembly manifest.json` identifies all 22 printed parts and hardware; `LEGO parts.csv` is the hardware inventory.

Print `Print plate 1.stl` and `Print plate 2.stl`, or use the individually oriented files in `Print parts`. Inspect support placement around the original clutch fork. Do not assume these plates are support-free. Axle bores face vertically in the supplied orientations. Assemble with LEGO friction pins; each base-mounted bearing uses at least two pins. Use 3 elastic bands.

Slide the bolt into the integral front-bridge guide before installing the rear bridge. Install the follower and cam, then the return band. The cam withdraws the bolt 5.2 mm. Only relock with the storage/test carriage at one of its end pockets. Check free motion by hand before applying drive torque.

Current geometric results are recorded in `Printed clearance checks.json`, `Lock checks.json` and `Print checks.json`. These do not validate loaded operation or ABS tolerances. The actuator's physical reliability remains under test.

## Rebuild

Use Python with `Source/requirements.txt` and an installed LDraw library. Run `Source/build.py`, `Source/print_layout.py`, then `Source/publish.py`; run the check scripts after changes. Rebuild ../register first; this rig takes its K and W components directly from that assembly. No slicer application is required.

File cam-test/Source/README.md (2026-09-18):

See ../README.md for rebuild and assembly instructions. The shared actuator source is ../../multiplexer; no obsolete input meshes are embedded here. Cam-test additionally depends on ../../register. LDraw geometry is read from the local installation; set LDRAW_DIR if necessary.

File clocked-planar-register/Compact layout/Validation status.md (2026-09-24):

# Current compact-register evidence

Geometry: `b9269d5256fb8a977353c3f6b3a8afbf76b6aba4205329548a5e14fee67b4e86`.

The current model is **not fully mechanically qualified**. The nominal geometry and sequencing checks below have been run; the unresolved native worm geometry and unmeasured loaded behavior prevent a full-machine sign-off. Neither successful animation nor a zero sampled-intersection count establishes force, tolerance or endurance performance.

## Corrections incorporated

- Corrected the master/slave power-path rotation signs and checked actual Q shaft velocity. Both settled Q directions have unit speed magnitude relative to POWER.
- Replaced fixed backlash delays with native dog angular windows. Disconnected input forks can wait for alignment through 4 mm of one-sided float; withdrawal remains positive.
- Returned gate gears alongside their LEGO connectors and offset only the clutch fingers. Their rear guides retain their compact locations. Cleared the gear sweeps from the fork shoulders.
- Added opposing nominal thrust restraints to all 16 routing shaft stacks, corrected connector insertion lengths and eliminated native pin-collar clashes.
- Turned the D input header mesh around its receiving shaft toward +Y. This clears the full master ring sweep without an extra gear or greater overall depth. Minimum radial envelope gap for the checked D parts is 3.82 mm, or 3.32 mm after the assumed 0.25 mm error on each part.
- Replaced the WRITE-side data shaft with a stock LEGO 4L axle. It has 6 mm nominal overlap in the 8T header gear and 8 mm in the receiving gear, leaving 4 mm between independent shaft ends. No shaft pairs have a nominal end gap below 0.5 mm in the current screen.
- Split the rear clock-pivot bearing from the base and attached it with two non-collinear friction pins. This removes the roughly 31 mm unsupported base ledge. Reinforced the bridge around the rear bush within the existing Y envelope.
- Selected print orientations using layer connectivity before face area, retaining bearing-flat carriage orientations and the pivot bridge's Y-positive flat orientation.
- Updated the animation, port labels and axes. The viewer uses the same corrected poses as the printed-motion checks. Repeated publication no longer duplicates the animation code.

The complete reference-pose envelope remains **278.4 × 127.2 mm in XZ**, **50.42% smaller** than the earlier assembly; Y depth is **76.23 mm**. This is not a swept packaging envelope.

## Current checks

| Check | Result | Scope |
|---|---|---|
| Defined transition behavior | 112 nominal cases; no wrong defined Q, modelled stalls or driven inserted bolts | All 56 distinct D/WRITE/CLK transitions, both initial Q values; quasi-static assumptions |
| Timing sensitivity | 1,120 cases; zero wrong defined Q, modelled stalls or driven inserted bolts | Eight running-phase offsets and two additional pickup limits; no inertia or measured friction |
| Printed moving solids | 56,112 frames, 10,352 unique poses, 53,841 narrow checks; zero intersections | All printed pairs, including levers; finite sampling |
| Native/native surfaces | 36,916 unique assembly poses from all 56,112 frames; 105 contact pairs retained for interface review | No pair whitelist; includes intended keyed/coaxial hardware interfaces and unresolved worm contacts |
| Native clutch dogs | 41,253 distinct dense relative poses; zero surface crossings | Every 2-degree integration step; actual shallow-entry surfaces, not a full-load test |
| Native/printed rotation envelopes | Four potential contacts, all reaction-gear/lever working interfaces | Whole revolutions at sampled relative poses; working interfaces resolved separately by the actuator contact solver |
| External gears and animation | 15 external meshes, unit-magnitude ratios; 105 direction checks pass | Mesh profiles and rotation signs |
| Shaft supports | No unsupported shaft in the 23-shaft radial screen | Presence of supports, not their load capacity |
| Axial restraint | All 16 routing stacks have opposing nominal thrust faces | Does not establish bush/connector grip |
| Printed grounding | No fixed printed component lacks a pin path to the frame | Connection geometry, not pin strength |
| Fork float | 780 states and 8,148 checks; zero printed intersections | Includes full 4 mm lost motion and both bar ends |
| Cam/disconnect order | Positive-withdrawal implication holds continuously; minimum screened bolt clearance about 0.384 mm | Assumed ±1 mm pickup, ±0.25 mm cam phase and 0.2 mm vertical error; excludes loaded deformation |

Native/native results were retained after the pivot reinforcement only after exact comparison established that every native triangle, native metadata other than storage offsets, and every recorded operation case was unchanged. That scope proof is recorded inside `Native motion surface screening.json`. Printed/printed and native/printed checks were rerun for the reinforced bridge.

Twenty-four simultaneous input/rising-clock cases violate setup/hold and do not receive a guaranteed Q value. Four nominal cases leave the master outside a bolt pocket. These are not qualified asynchronous captures. The model also assumes instantaneous spring insertion after angular alignment and stationary disconnected shafts; rapid repeated clocks, coasting and loaded release remain unqualified.

The static construction-reference pose puts both carriages in mid-travel with bolts lowered and is not an operating pose. Its two bolt/carriage intersections are reported separately; operating checks use the actual bolt/carriage relationship.

## Load and print findings

The lossless 0.1 Nm blocked-clock bound gives 200 N at the actuator and 80 N at the common bar. The two printed amplifier plates have estimated peak nominal bending stresses of 8.38 and 14.10 MPa, with approximately 0.146 mm ideal relative output deflection. These are variable-section beam calculations, not contact FEA or measured performance.

The rear pivot bridge was reinforced after its initial 70 N screen gave approximately 34 MPa. The final bridge is screened at **120 N**, assigning the entire pivot reaction to it: **16.37 MPa** peak nominal bending and **0.154 mm** ideal central deflection. The calculation omits joint compliance, offset-pin torsion, local bearing/notch effects, creep and fatigue. The assumed modulus is 1,890 MPa; supplier specimen properties are not part allowables. LEGO shaft/pin material allowables and loaded grip are not established.

All generated printed parts are connected, watertight solids. At 0.2 mm layers, only the common fork/cam bar retains disconnected-layer features (three in the selected screen); it requires support or a further print-specific redesign. The base halves and flat pivot bridge have no disconnected layers. The former large base ledge is removed, but pin-hole bridges, collar lips, bearing finish and fit still need print-process confirmation. No Bambu Studio operation was used.

## Blockers to full mechanical qualification

1. **Inherited worm/reaction geometry:** the 32,400-combination assembly-phase screen found 23 sampled wheel poses with no nonintersecting sampled worm phase. This means the supplied meshes cannot certify those poses. It does not establish that real LEGO gears jam. Trimming the meshes or silently exempting them would not resolve this. Confirmation with the already-printed multiplexer, or more faithful physical tooth geometry, is needed to distinguish a mesh approximation from an actuator-spacing problem.
2. **Loaded dynamics and strength:** no measured clutch withdrawal force at 0.1 Nm, band force/preload, joint grip, motor acceleration/coasting or part-level material strength is available. The quasi-static model cannot validate these by assigning arbitrary favorable values.
3. **Continuous tolerance and manufacturing qualification:** finite motion sampling and selected analytic bounds do not cover every intermediate all-part tolerance combination. Common-bar supports, hole bridging and actual printed fits remain to be qualified.

`Qualification summary.json` therefore remains fail-closed. A full working/print-release claim is not supported by the present evidence.

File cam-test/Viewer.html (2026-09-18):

# Two-actuator cam test rig

162 × 82 mm base · 22 printed parts · two input axles. The CAM CONTROL actuator moves the cam; its clutch drives the test actuator only after the bolt withdraws.

Inspect Focus Show supportsAxle labelsReset cameraTop view

Part Inspect cam travel

Play explanationRestartExplode lock partsSequence Hide lock bridgesExplain pins

Play to see HOLD → unlock → drive the test actuator → relock. The animation illustrates the intended sequence, not forces or measured timing.

The yellow cam moves the bolt through its follower pin. The bolt guide is part of the front bridge; return-band anchors are part of the rear bridge.

Drag to rotate · Shift/right-drag to pan · Scroll to zoom.

## Bench test

1. With TEST DRIVE stopped, turn CAM CONTROL to withdraw the bolt and engage the clutch.
2. Turn TEST DRIVE slowly until the test carriage reaches an end. Reverse it and check travel to the other end.
3. At either end, return CAM CONTROL to HOLD. The clutch disconnects before the bolt seats. Turning TEST DRIVE should now leave the test carriage still.
4. Stop both inputs. Gently test carriage holding and cam-control backlash by hand; then unlock and repeat at the other end.

Do not relock with the test carriage between its two end pockets. Keep the test drive set to the selected end while relocking.

Print plate 1 · base · Print plate 2 · components · Build and test guide · LEGO inventory

Physical fit, band tension and loaded timing remain bench-test questions. No output-enable stage, storage power train or register output clutch is included. Three elastic bands: one per actuator and one for the locking bolt.

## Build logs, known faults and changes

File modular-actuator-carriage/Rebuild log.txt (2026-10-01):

Waiting for the shared geometry slot.
CPU throttle: 50 ms running, 450 ms paused; one worker, low priority.
Geometry job: single TBB/BLAS worker, low priority, 1.2 GiB memory guard.
Running build.py
[{'part': 'Carriage control rod', 'old_faces': 1386, 'new_faces': 2206, 'removed_mm3': 36.741009272285375, 'added_mm3': 36.74102460736748, 'watertight': True, 'solids': 1}, {'part': 'Lock control rod', 'old_faces': 2104, 'new_faces': 2866, 'removed_mm3': 36.741006243472064, 'added_mm3': 36.74101425433631, 'watertight': True, 'solids': 1}]
Updated both carriage meshes.
Running check.py
QUALITY [{'part': 'Carriage body', 'watertight': True, 'solids': 1}, {'part': 'Carriage bearing end', 'watertight': True, 'solids': 1}, {'part': 'Upper actuator cheek', 'watertight': True, 'solids': 1}, {'part': 'Lower actuator cheek', 'watertight': True, 'solids': 1}, {'part': 'Actuator lever', 'watertight': True, 'solids': 1}, {'part': 'Locking bolt', 'watertight': True, 'solids': 1}, {'part': 'Locking bolt guide', 'watertight': True, 'solids': 1}, {'part': 'Carriage control rod', 'watertight': True, 'solids': 1}, {'part': 'Lock control rod', 'watertight': True, 'solids': 1}, {'part': 'Left bearing wall', 'watertight': True, 'solids': 1}, {'part': 'Right bearing wall', 'watertight': True, 'solids': 1}, {'part': 'Module base', 'watertight': True, 'solids': 1}]
PRINTED []
HARDWARE []
BANDS []
Neighbour displacement checked (72, 0, 0)
Neighbour displacement checked (0, 0, 64)
Neighbour displacement checked (72, 0, 64)
Neighbour displacement checked (-72, 0, 64)
{
  "passed": true,
  "pitch_X_mm": 72,
  "pitch_Z_mm": 64,
  "poses_per_row": 27,
  "vertical_pose_combinations": 729,
  "boolean_tests": 1170,
  "hits": [],
  "quality": [
    {
      "part": "Module base",
      "watertight": true,
      "solids": 1,
      "bounds": [
        [
          -31.5,
          32.0,
          -8.0
        ],
        [
          40.5,
          48.4,
          56.0
        ]
      ]
    },
    {
      "part": "Horizontal frame bridge",
      "watertight": true,
      "solids": 1,
      "bounds": [
        [
          -4.5,
          32.5,
          -3.8
        ],
        [
          15.5,
          40.3,
          4.5
        ]
      ]
    },
    {
      "part": "Vertical frame bridge",
      "watertight": true,
      "solids": 1,
      "bounds": [
        [
          -4.5,
          32.5,
          -3.8
        ],
        [
          4.5,
          40.3,
          20.5
        ]
      ]
    },
    {
      "part": "Centre frame bridge",
      "watertight": true,
      "solids": 1,
      "bounds": [
        [
          -4.5,
          32.5,
          -3.8
        ],
        [
          15.5,
          40.3,
          20.5
        ]
      ]
    }
  ],
  "scope": "Same orientation, 2x2. Corresponding rods coupled along X; rows can move independently. Nominal pin compression excluded by 2.45 mm shaft-radius proxies; no strength or drive-torque claim."
}
Assembly access {'passed': True, 'boolean_tests': 986, 'hits': [], 'sequence': 'Preinstall 2L frame pins, press bridges +Y, then insert 4274 rod pins +Y. Rod-pin lip compression through intended holes is excluded during insertion.'}
Running assembly.py
Right half from -Y with actuator complete and worm positioned {}
Left half from -X toward positioned right half {}
Preload rod attachment pin into carriage from -Y {}
Preload rod attachment pin into carriage from -Y {}
Control rod from -Y onto preloaded pins {}
PASSED True
Running printcheck.py
Carriage control rod [[6.4, 50.415, [3.3664648085832596, 0.0, 84.233533680439, 8.0]], [6.6, 6.079, [3.212912268936634, 6.602000571787357, 12.387086197733879, 8.0]]]
Passed print-oriented layer-area comparison for Carriage control rod
Lock control rod [[10.6, 20.542, [3.3664648085832596, 3.999999761581421, 84.233533680439, 10.40000033378601]], [10.8, 6.079, [3.212912268936634, 10.602000333368778, 12.387086197733879, 11.999999761581421]]]
Passed print-oriented layer-area comparison for Lock control rod
REBUILD AND CAD CHECKS PASSED. Output: /Users/zac/Documents/ChatGPT/lego designs 2_/current-designs/modular-actuator-carriage/Source/build

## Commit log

2026-09-17 Add current multiplexer, register, adder and assembly designs
    [01 controls-tray direct bores.stl, 02 controls-cap direct bores.stl, 03 bit-tray direct bores.stl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]
2026-09-17 Finalize compact multiplexer and printable assembly
    [A idler bearing - print.stl, A idler bearing.stl, Base - print.stl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]
2026-09-17 Extend selector input axle to 11 studs
    [LEGO parts.csv]
2026-09-17 Replace register with compact integrated-bridge lock prototype
    [01 controls-tray direct bores.stl, 02 controls-cap direct bores.stl, 03 bit-tray direct bores.stl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]
2026-09-17 Secure every register bearing with at least two base pins
    [Base.stl, E port bearing.stl, LEGO parts.csv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]
2026-09-17 Save single-level adder review draft with unresolved clearance findings
    [Base.stl, Bearing fit coupon.stl, Bearing wall X-28 three holes.stl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]
2026-09-18 Consolidate into four current designs using repaired actuator components
    [A H service lower bearing cheek 0.stl, A H service lower bearing cheek 1.stl, A H service lower bearing cheek 2.stl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]
2026-09-18 Clear adder pivot axles through full carriage travel
    [C Left carriage half.stl, P Left carriage half.stl, X Left carriage half.stl]
2026-09-19 Finalize working multiplexer and retain reusable validation checks
    [Complete print layout.stl, Direct lever and band cleat - print.stl, Direct lever and band cleat.stl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]
2026-09-22 Make aligned 16T multiplexer the sole current design
    [A idler bearing - print.stl, A idler bearing.stl, Base - print.stl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]
2026-09-22 Restore original multiplexer generator and byte-exact rebuild
    [Carriage fork and roof.stl, Clutch stock.stl, Common baseboard.stl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]
2026-09-23 Preserve planar latch and isolate clocked register development
    [Bolt.stl, Cam profile coupon.stl, Carriage fork and roof.stl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]
2026-09-24 Add compact clocked planar register and mechanical validation tooling
    [Base left.stl, Base middle.stl, Base right.stl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]
2026-10-01 Preserve modular actuator-carriage design with reproducible build and validation
    [2x2 frame connectors print layout.stl, Actuator lever print.stl, Actuator lever.stl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]
2026-10-02 Archive superseded designs and clarify the two active module entry points
    [Base left.stl, Base middle.stl, Base right.stl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]
